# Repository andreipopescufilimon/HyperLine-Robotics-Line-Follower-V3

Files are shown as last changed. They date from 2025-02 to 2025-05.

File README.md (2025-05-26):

# HyperLine Robotics (HLR) V3 - Line Follower Robot

## 🚀 About the Project
The **JSumo HyperLine Robotics (HLR) V3** is an advanced, high-speed **line follower robot** built for competitions. This version is the result of 3 years of prototyping, optimizing both speed and precision without relying on external downforce like an EDF or impeller. As a member of the **JSumo Team**, I have combined **lightweight engineering, high-speed motors, and custom-built sensors and chassis** to achieve high performance.

<p align="center">
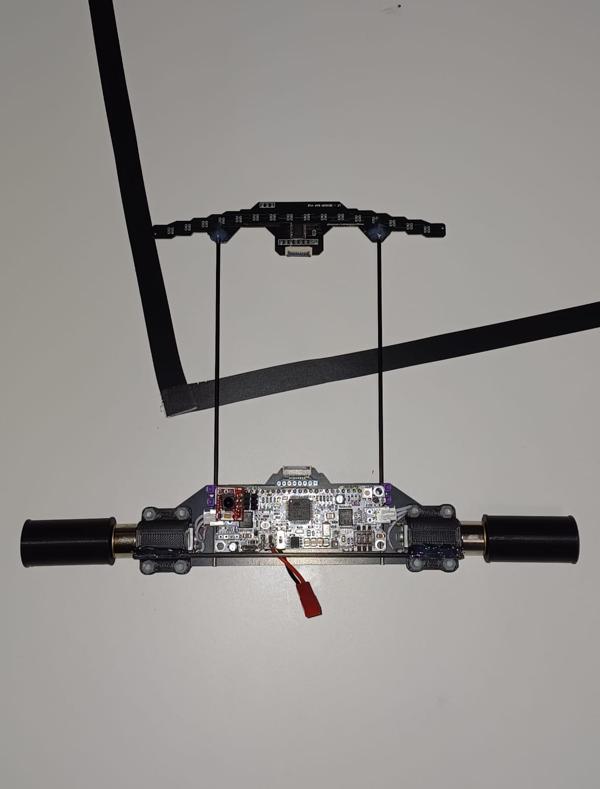
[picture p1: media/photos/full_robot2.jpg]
HyperLine Robotics V3
  
</p>

### **Key Advantages Over Previous Versions**
- **No additional downforce** – Traditional high-speed line followers use EDFs to generate downforce, but HyperLine Robotics V3 achieves comparable speeds **without any additional generated weight**, based on comparisons with a **300g EDF-powered robot (V2)**.
- **Ultra-lightweight design** – The robot is engineered to be significantly light, ensuring agile movements and optimized acceleration.
- **Custom 16-sensor array** – Precision-designed for maximum accuracy, this sensor array system ensures fast detection of the track at all speeds, by using it with our public library.
- **Optimized PCB chassis** – The **chassis PCB** integrates all components efficiently, reducing weight and improving weight balance.
- **Lightweight carbon fiber bars & FPC cables** – The **2mm carbon fiber bars** and **FPC (Flexible Printed Circuit) cable** are used to connect the sensors to main PCB chassis, reducing weight while maintaining structural integrity.
- **Custom-built motor mounts & wheels** – The **motor mounts** and **wheel rims** are custom-manufactured from **3D printed using CF PLA (Carbon Fiber PLA)** for improved durability.

---

## 🔬 **Technical Details & Features**

### **📌 Lightweight**
HyperLine Robotics V3 is engineered to maintain **top speeds comparable to a 300g robot with EDF downforce**, yet it remains **significantly lighter at around 100g**. The key innovation lies in:
- **Optimized weight distribution** – Eliminating unnecessary materials while maintaining structural integrity.
- **High-efficiency silicone wheels** – Ensuring superior grip without extra weight.
- **Advanced motor tuning** – Maximizing power output without requiring additional stabilization, while minimizing vibrations.

### **🎯 Custom-Built 16-Sensor Array**
One of the standout features of HLR V3 is its **custom-designed sensor array**, which drastically improves track detection accuracy:
- **16 individual sensors** for high-resolution tracking.
- **Custom Multiplexer Integration** – Reducing processing overhead and increasing reaction speed.
- **Adaptive Calibration** – Ensuring maximum reliability across different competition conditions.
- **Custom sensor development** – Full details and design can be found in the **my official repository**: [Line Follower 16-Sensors Bar with Multiplexor](https://github.com/andreipopescufilimon/Line-Follower-16-Sensors-Bar-with-Multiplexor)

---

## 🔧 **Components & Specifications**

| Component | Description | Image |
|---|---|---|
| **JSumo XMotion** | Motor control & processing unit |  |
| **JSumo ProFast Motors** | High-speed motors optimized for competitions |  |
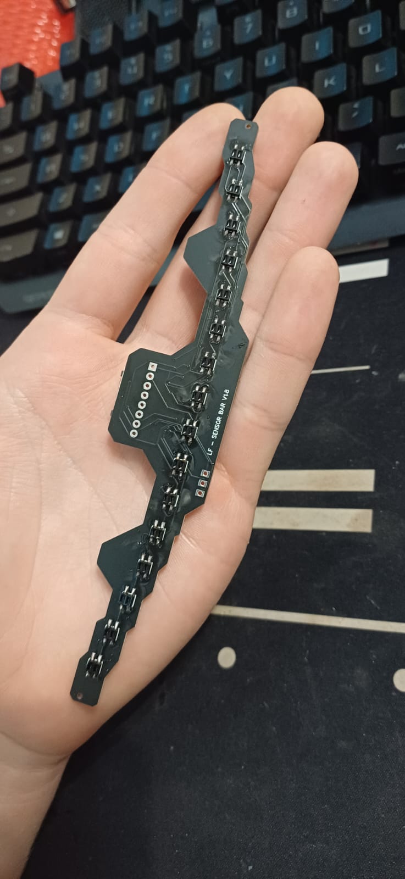
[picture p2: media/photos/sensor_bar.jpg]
| **Custom 16-Sensor Array** | High-precision line detection system |  |
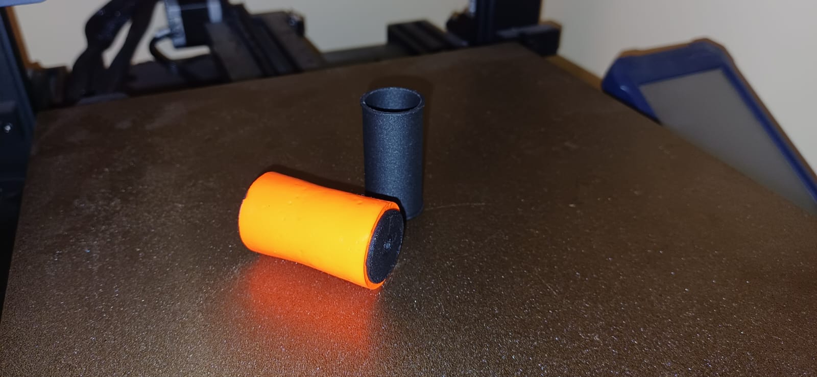
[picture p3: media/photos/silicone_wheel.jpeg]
| **Custom Silicone Wheels** | Designed for optimized grip and durability |  |
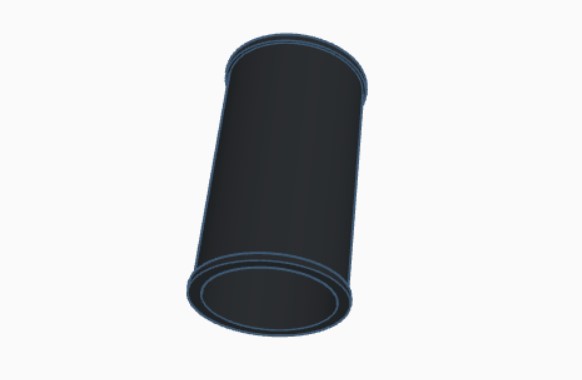
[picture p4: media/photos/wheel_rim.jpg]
| **Custom Wheel RIms** | Designed for optimized strength at high RPM |  |
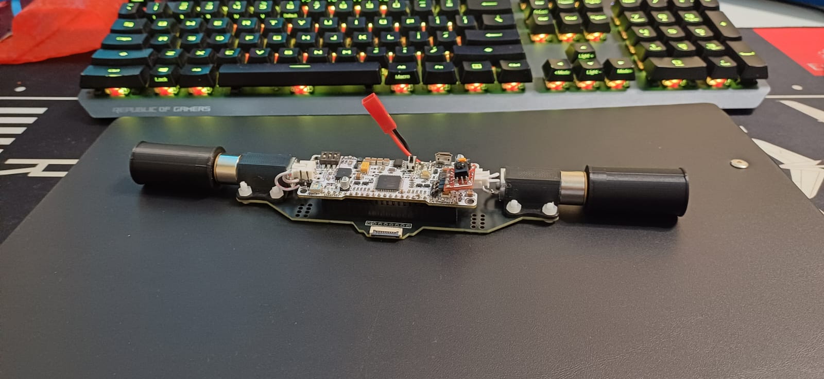
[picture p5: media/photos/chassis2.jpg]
| **Custom Chassis PCB** | Lightweight and efficient layout |  |
| **Lightweight Carbon Fiber Bars** | 2mm carbon fiber bars for structural efficiency |  - |
| **FPC Cables** | Lightweight flexible PCB cables for sensor connections | - |
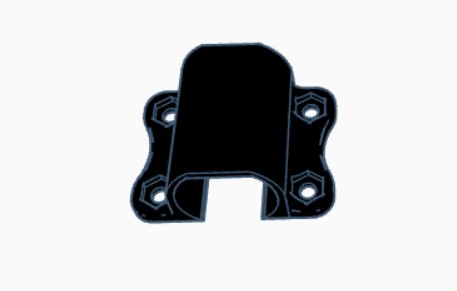
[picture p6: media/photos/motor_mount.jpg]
| **Custom Motor Mounts** | 3D-printed with CF PLA for enhanced precision |  |

---

## 🏆 **Performance & Upcoming Competitions**
With these innovations, HyperLine Robotics V3 has achieved performance levels **comparable to heavier EDF-powered robots**. The **perfect balance of speed, weight, and precision** allows it to compete.

HyperLine Robotics V3 competed in the **InfoMatrix World Final** where I won with it by over 2sec.

---

## 📂 **Repository & Documentation**
🔗 **16-Sensor Bar Repository:**  
[Line Follower 16-Sensors Bar with Multiplexor](https://github.com/andreipopescufilimon/Line-Follower-16-Sensors-Bar-with-Multiplexor) 

🔗 **16-Sensor Bar Library Repository:**  
[Line Follower 16-Sensors Bar Library](https://github.com/andreipopescufilimon/LF-Sensor-Bar-Library)

---

## 🌍 **International Collaboration – JSumo Team**
Despite being from Romania, I am a member of the **JSumo Team**, a globally recognized leader in robotics competitions. With this collaboration I have the unique opportunity to collaborate with a high level team, access cutting-edge resources, and experiment with innovative technologies.

---

## 🎥 **Media**

Watch the video (https://www.youtube.com/watch?v=Agkfs_FI15A)

---

📧 **Email:** [hyperlinerobotics@gmail.com](mailto:hyperlinerobotics@gmail.com)  
🌐 **HyperLine Robotics Website:** [HyperLine Robotics](https://hyperlinerobotics.com/) <br> 
🌐 **JSumo Website:** [JSumo](https://jsumo.com/)

A special thanks to **JSumo**, for their invaluable support!  
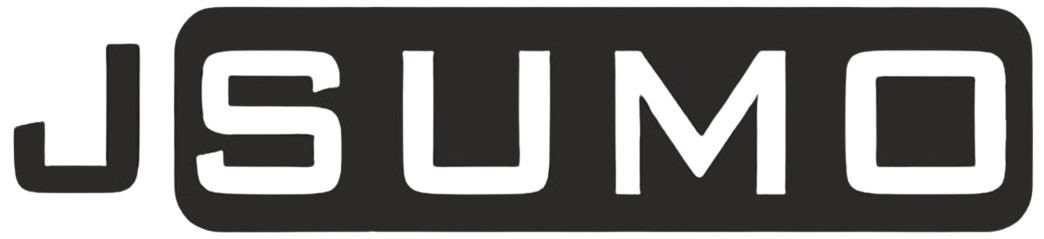
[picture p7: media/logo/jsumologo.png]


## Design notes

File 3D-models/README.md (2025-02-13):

# 3D-models - 3D Models

This folder contains 3D design files for the robot's components. Formats include STL files.

## Contents

### Main Models
- `wheel_rim.stl` - wheel rim design with D shape axle
- `motor_support.stl` - motor support, to attach it to the chassis
- `sensorbar_spacer.stl` - sensor bar spacer from the ground
- `sensorbar_mount.stl` - sensor bar mount to carbon fiber bars

## Usage
- Download the `.stl` files to fabricate the components using a 3D printer or CNC machine.
- Ensure the parts are assembled according to the robot's full assembled design.

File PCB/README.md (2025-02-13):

# PCB - PCB and electrical schematics files

This folder contains the PCBs, circuit diagrams and wiring layouts for the robot's electronics.

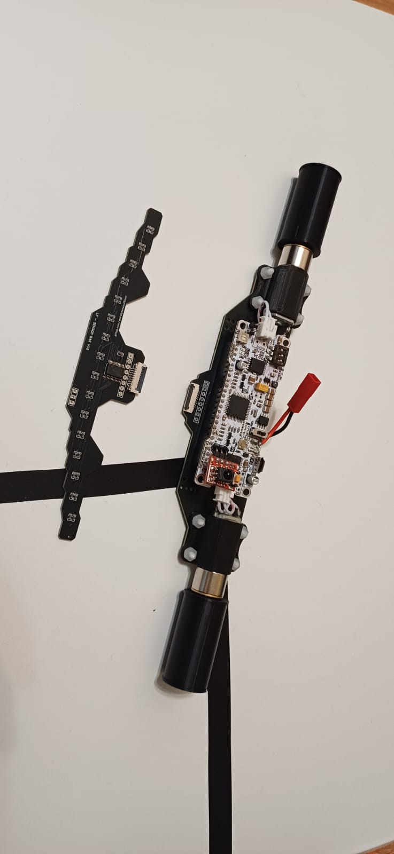
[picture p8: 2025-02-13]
media/photos/chassis_and_sensors.jpg

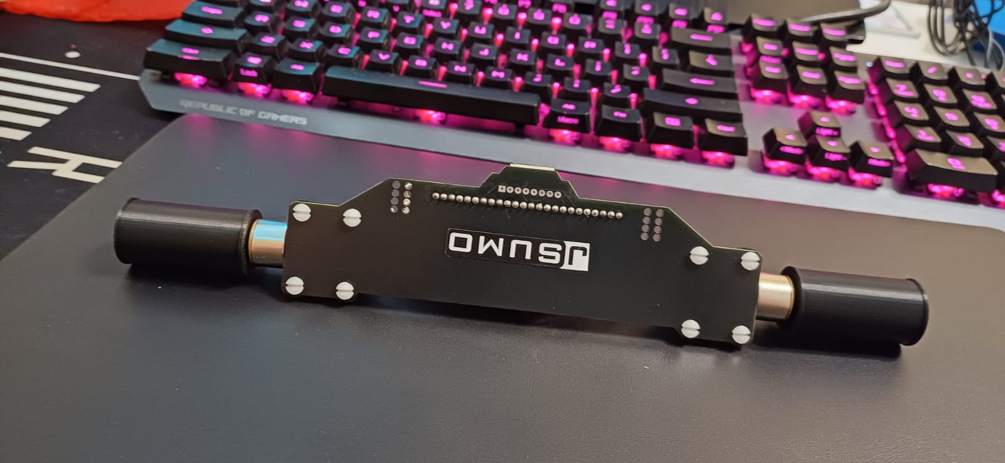
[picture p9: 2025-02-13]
media/photos/chassis1.jpg

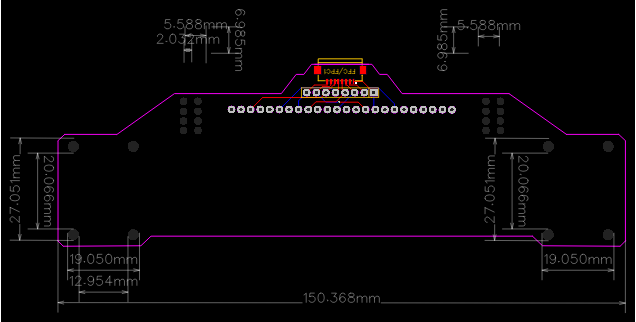
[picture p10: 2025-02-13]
PCB/chassis/chassis.png

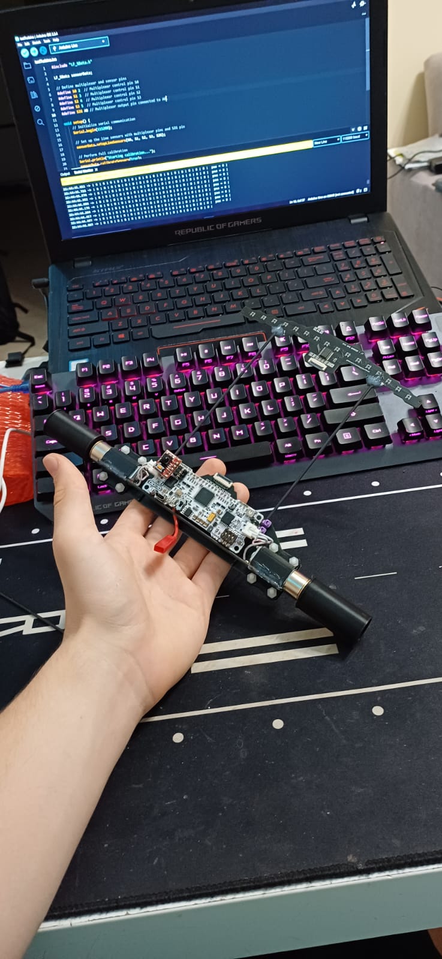
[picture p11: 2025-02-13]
media/photos/full_robot1.jpg

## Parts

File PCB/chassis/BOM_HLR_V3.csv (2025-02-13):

ID | Name | Designator | Footprint | Quantity | Manufacturer Part | Manufacturer | Supplier | Supplier Part | Price
1 | OUT | +1 | HEADER - HEADER-FEMALE-2.54_1X8 ANGELO | 1
2 | FH12-08S-1SH | FFC/FPC1 | FPC-SMD_8P-P1.00_FH12S-8S-1SH-55 | 1 |  |  | LCSC | C262755 | 0.135

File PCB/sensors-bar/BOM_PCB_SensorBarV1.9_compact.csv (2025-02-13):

ID | Name | Designator | Footprint | Quantity | Manufacturer Part | Manufacturer | Supplier | Supplier Part | Price
1 | QRE1113GR | S1,S2,S3,S4,S5,S6,S7,S8,S9,S10,S11,S12,S13,S14,S15,S16 | OPTO-SMD_QRE1113GR | 16 |  |  | LCSC | C232862 | 0.712
2 | SSOP-24_L8.1-W5.3-P0.65-LS7.8-BL | MUX | SSOP-24_L8.1-W5.3-P0.65-LS7.8-BL | 1 |  |  | LCSC | C98457 | 0.477
3 | 0.1u | C1 | C0603 | 1 |  |  | LCSC | C6119867 | 0.002
4 | FH12-08S-1SH | FFC/FPC | FPC-SMD_8P-P1.00_FH12S-8S-1SH-55 | 1 |  |  | LCSC | C262755 | 0.122
5 | 47kΩ | R1,R3,R5,R7,R9,R11,R13,R15,R17,R19,R21,R23,R25,R27,R29,R31 | R0603 | 16 |  |  | LCSC | C25819 | 0.001
6 | 220Ω | R2,R4,R6,R8,R10,R12,R14,R16,R18,R20,R22,R24,R26,R28,R30,R32 | R0603 | 16 |  |  | LCSC | C22962 | 0.001
7 | DIST_S 2.54 1X3 | D | HEADER - HEADER-FEMALE-2.54_1X3 | 1
8 | OUT | + | HEADER - HEADER-FEMALE-2.54_1X8 ANGELO | 1

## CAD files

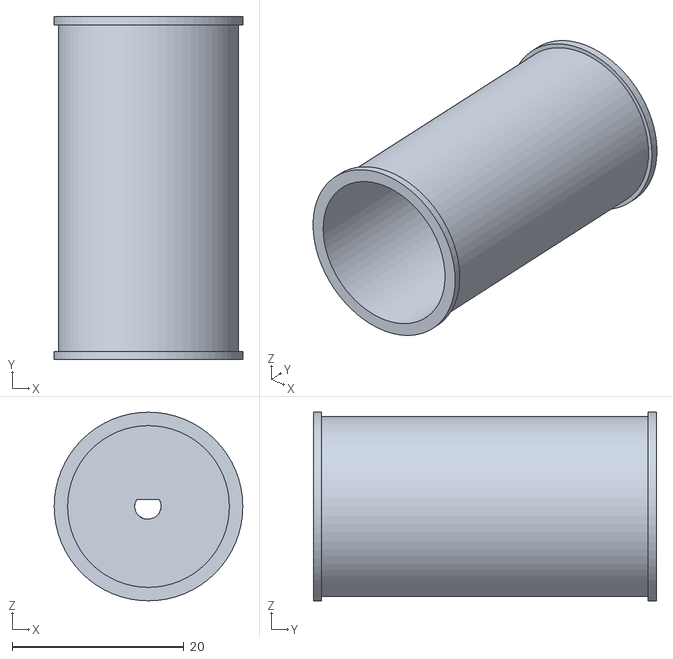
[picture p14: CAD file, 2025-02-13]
3D-models/wheel_rim.stl
22.0 x 40.0 x 22.0

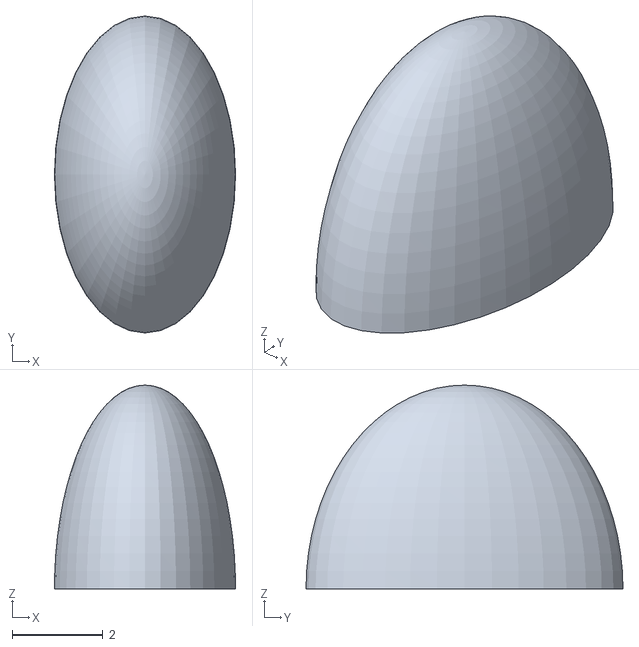
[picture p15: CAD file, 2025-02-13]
3D-models/sensorbar_spacer.stl
4.00 x 7.00 x 4.50

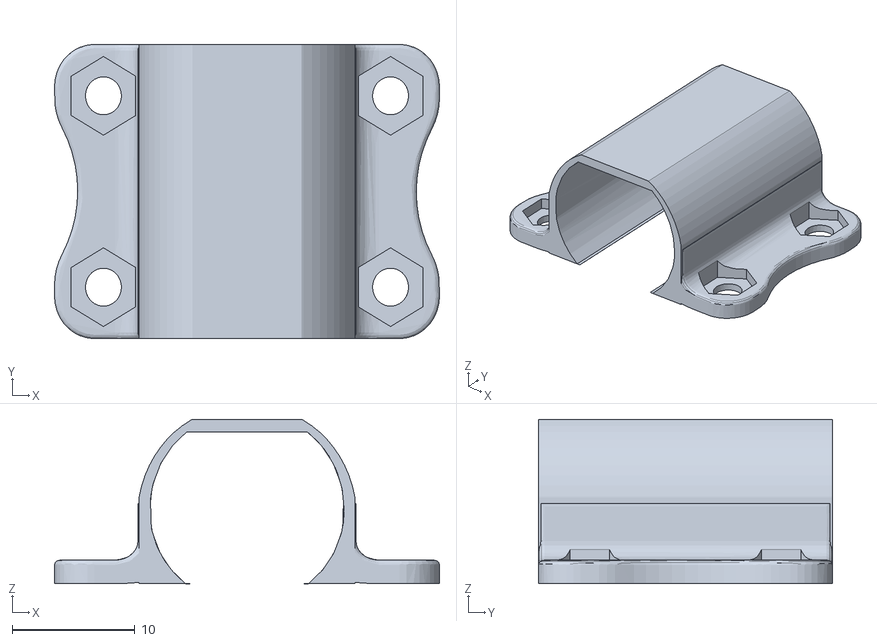
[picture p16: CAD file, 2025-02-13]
3D-models/motor_support.stl
31.4 x 24.0 x 13.4

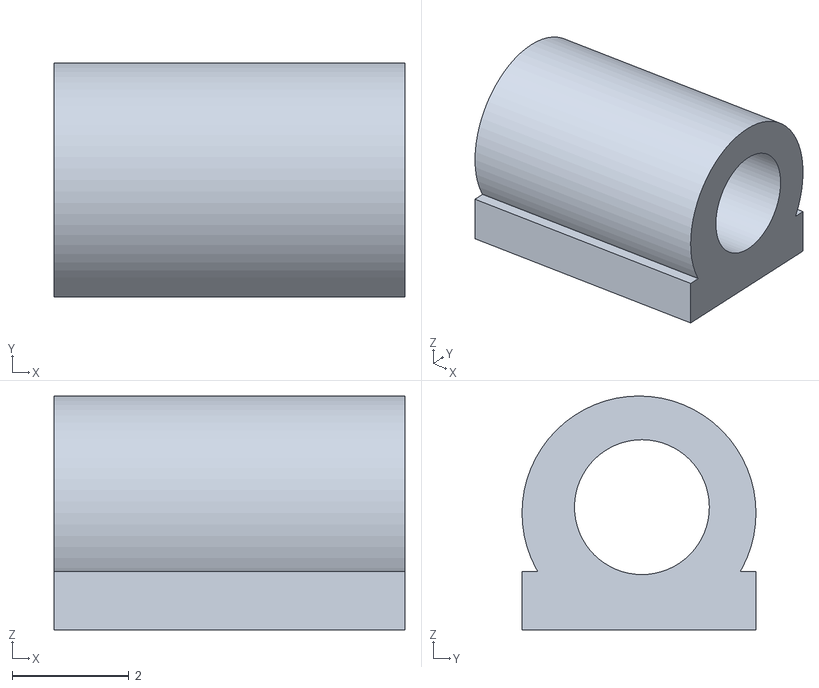
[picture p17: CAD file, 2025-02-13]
3D-models/sensorbar_mount.stl
6.00 x 4.00 x 4.00

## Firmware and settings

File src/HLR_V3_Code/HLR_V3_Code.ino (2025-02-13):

/* 
  > LF No Downforce
  > EDF/impeller off

  Last edited: 13th February 2025
  Last edited by: Popescu Filimon Andrei Cosmin
*/

#include "LF_SData.h"
#include "xmotionV3.h"

LF_SData lf_sdata;

#define DISTANCE_PIN A1
#define S0_PIN 0
#define S1_PIN 1
#define S2_PIN 2
#define S3_PIN 4
#define SIG_PIN A5

#define Start A0
#define DipSwitch1 5  // Dipswitch 1 for calibration mode
#define DipSwitch2 6  // Dipswitch 2 for debug mode
#define DipSwitch3 7  // Dipswitch 3 for safe mode

// PID constants
#define KP 0.22
#define KI 0.008
#define KD 9.2

float previousError = 0;
float integral = 0;

int setBaseSpeed = 0, baseSpeed = 0;
int setMaxSpeed = 0, maxSpeed = 0;

// Variables to store the last six error values for smoother KI calculation
int error1 = 0, error2 = 0, error3 = 0, error4 = 0, error5 = 0, error6 = 0;
unsigned long startTime = 0, currentTime = 0, elapsedTime = 0, accelerationTime = 500;

void setup() {
  xmotion.UserLed1(100);

  // Setup pin modes for dip switches and start button
  pinMode(DipSwitch1, INPUT_PULLUP);
  pinMode(DipSwitch2, INPUT_PULLUP);
  pinMode(DipSwitch3, INPUT_PULLUP);
  pinMode(Start, INPUT_PULLUP);

  // Setup sensors and motors
  lf_sdata.setupDistanceSensor(DISTANCE_PIN);
  lf_sdata.setupLineSensors(S0_PIN, S1_PIN, S2_PIN, S3_PIN, SIG_PIN);


  // Determine mode based on dip switch settings
  if (digitalRead(DipSwitch3) == HIGH) {
    // Safe Run mode
    setBaseSpeed = 70;
    setMaxSpeed = 90;
  } else {
    setBaseSpeed = 90;
    setMaxSpeed = 100;
  }

  if (digitalRead(DipSwitch1) == HIGH && digitalRead(DipSwitch2) == LOW && digitalRead(DipSwitch3) == LOW) {
    // Calibration mode
    unsigned long startTime = millis();
    unsigned long calibrationTime = 5000;  // 5 seconds

    Serial.begin(9600);
    Serial.println("Starting calibration...");

    while (millis() - startTime < calibrationTime) {
      lf_sdata.calibrateSensors(true);
    }
    Serial.println("Calibration complete.");
  } else {
    lf_sdata.calibrateSensors(false);
  }

  xmotion.UserLed2(100);
  xmotion.SETUP();
  xmotion.ToggleLeds(100);

  if (digitalRead(DipSwitch2) == HIGH && digitalRead(DipSwitch1) == LOW && digitalRead(DipSwitch3) == LOW) {
    // Debug mode
    Serial.begin(9600);
  }
}

void loop() {
  if (startTime == 0) {
    startTime = millis();
  }

  elapsedTime = millis() - startTime;
  if (elapsedTime <= accelerationTime) {
    baseSpeed = map(elapsedTime, 0, accelerationTime, 0, setBaseSpeed);
    maxSpeed = map(elapsedTime, 0, accelerationTime, 0, setMaxSpeed);
  }

  long linePosition = lf_sdata.getLinePosition();
  float error = linePosition - 7500;

  // Update integral with last six errors for smoother calculation
  error6 = error5;
  error5 = error4;
  error4 = error3;
  error3 = error2;
  error2 = error1;
  error1 = error;
  //integral = error6 + error5 + error4 + error3 + error2 + error1 + error;
  integral = integral + error;

  float derivative = error - previousError;
  previousError = error;

  float correction = (KP * error) + (KI * integral) + (KD * derivative);

  int leftMotorSpeed = constrain(baseSpeed - correction, 0, maxSpeed);
  int rightMotorSpeed = constrain(baseSpeed + correction, 0, maxSpeed);

  if (digitalRead(DipSwitch2) == HIGH && digitalRead(DipSwitch1) == LOW && digitalRead(DipSwitch3) == LOW) {
    // Debug mode: print sensor data
    Serial.print("Line Position: ");
    Serial.println(linePosition);
  }

  if ((linePosition > 2000 && linePosition <= 4000) || (linePosition >= 11000 && linePosition < 13000)) {  // Medium turn
    baseSpeed = constrain(setBaseSpeed * 0.9, 50, setBaseSpeed);
    maxSpeed = constrain(setMaxSpeed * 0.9, 60, setMaxSpeed);
  } else {                     // Straight line
    baseSpeed = setBaseSpeed;  // Restore full speed
    maxSpeed = setMaxSpeed;
  }

  if (linePosition <= 2500) {
    xmotion.MotorControl(80, -70);
  } else if (linePosition >= 12500) {
    xmotion.MotorControl(-70, 80);
  } else {
    xmotion.MotorControl(map(leftMotorSpeed, 0, 100, 0, 255), map(rightMotorSpeed, 0, 100, 0, 255));
  }
}
